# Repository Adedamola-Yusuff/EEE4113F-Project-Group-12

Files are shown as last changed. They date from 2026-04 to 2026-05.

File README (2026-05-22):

# EEE4113F_Group12_PCB
## Overview
This repository was used for Group 12 (of the 2026 EEE4113F course from the University of Cape Town) to collaborate on the design of the B.A.R.B.I.E.

Buoy for<br>
Antarctic<br>
Research and<br>
Basic<br>
Information<br>
Exchange

See the README within each directory for more information.

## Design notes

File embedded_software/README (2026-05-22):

# EEE4113F_Group12_PCB - embedded software
## Overview
This directory contains the software for developing an embedded-program for the BARBIE.

## What is included
This repository includes:
- Simulation files
- Firmware
- Configuration headers

None of the generated compilation files are included.

## Installation & Dependencies
The simulation uses Python 3.13.

The firmware uses the ESP-IDF framework, flashed onto the ESP32 with the PlatformIO workflow and the ESP32's USB-JTAG interface.

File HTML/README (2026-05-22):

# EEE4113F_Group12_PCB - KiCAD files
## Overview
The HTML file contains the UI for the B.A.R.B.I.E called T.E.A.

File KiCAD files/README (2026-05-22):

# EEE4113F_Group12_PCB - KiCAD files
## Overview
This PCB was intended to eventually be sent to [JLCPCB](https://jlcpcb.com/) for printing.

## What is included
This repository includes:
- The Project file
- The Schematic file
- The PCB file
Apologies for the files being so messy.

None of the generated gerber files are included.

## Installation & Dependencies
The files were made with KiCAD 9.0, so the same or a later version of KiCAD is needed to open the files.

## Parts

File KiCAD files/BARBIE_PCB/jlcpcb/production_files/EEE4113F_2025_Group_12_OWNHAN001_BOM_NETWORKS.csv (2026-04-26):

Comment | Designator | Footprint | LCSC | Quantity
ESP32-S3-WROOM-1U-N8 | U1 | ESP32-S3-WROOM-1U_No_holes | C2980297 | 1
ATGM332D-5N71 | U3 | ATGM332D-5NR32 | C46955987 | 1
LORA-CC68-433MHz-TCXO | U2 | LORA-CC68-433MHz-TCXO | C5126744 | 1

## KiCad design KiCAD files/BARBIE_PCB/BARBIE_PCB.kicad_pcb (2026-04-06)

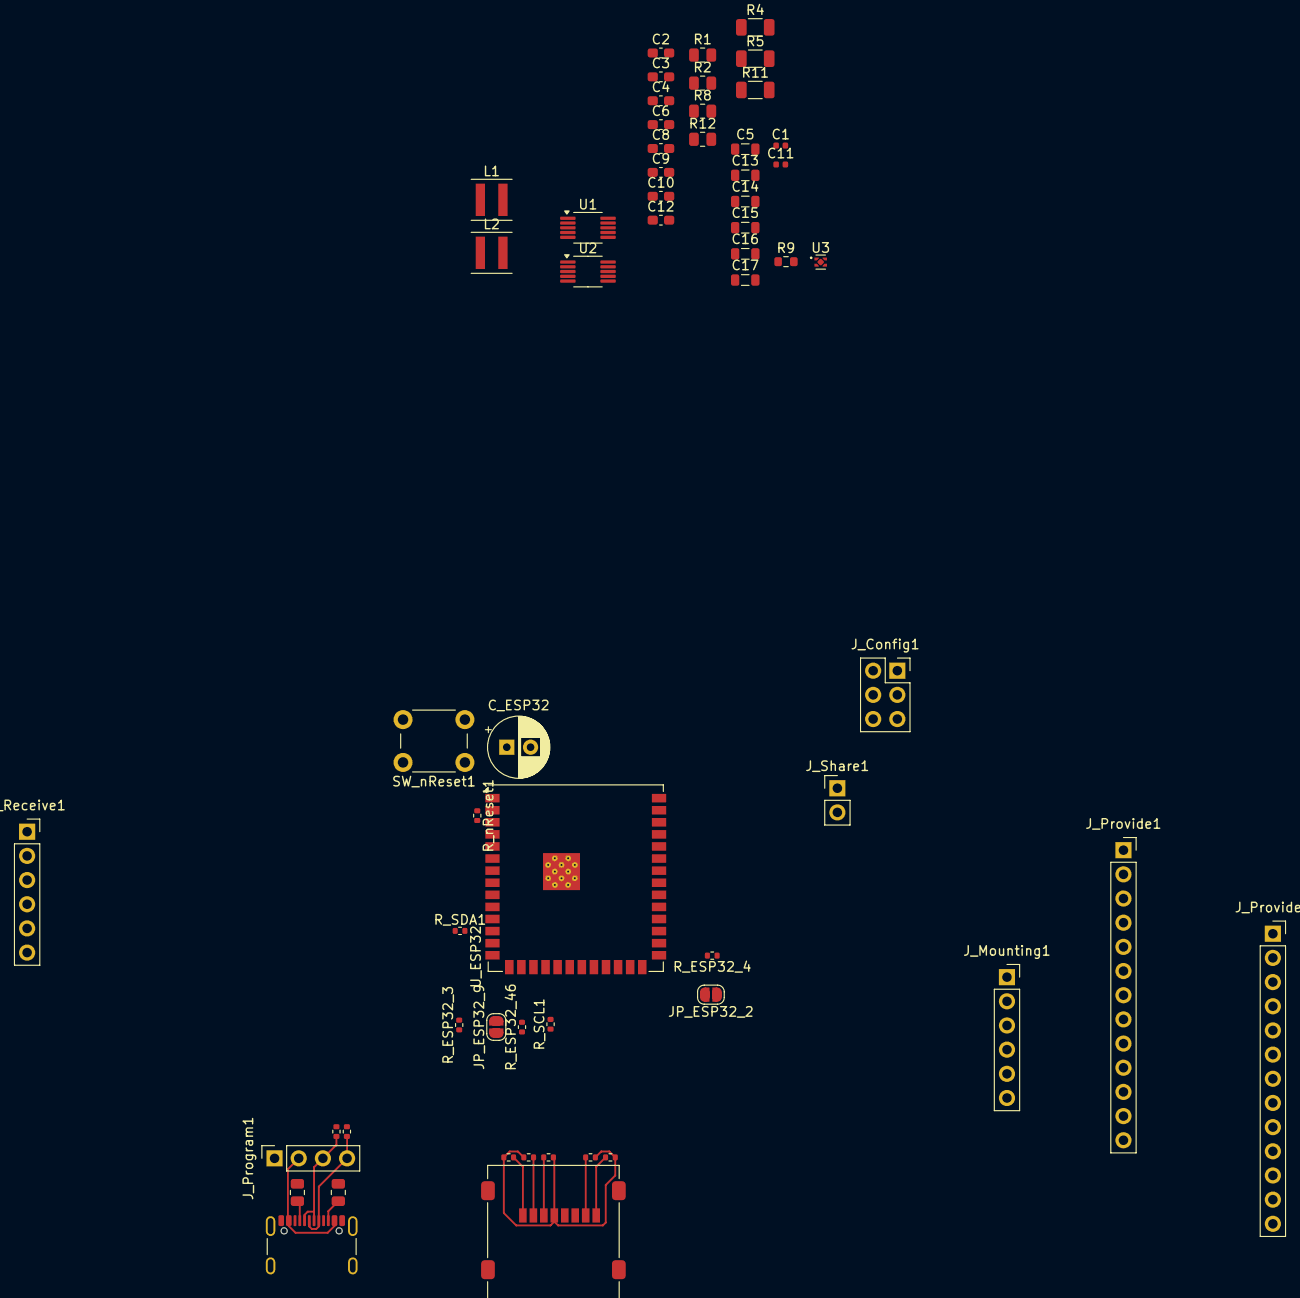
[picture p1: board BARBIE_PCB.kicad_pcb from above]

Board: 2 copper layers, 58 parts (0 on the bottom side), 56 nets.

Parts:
C1, C11: 100nF; L_0402_1005Metric
C2, C3, C4, C6, C8, C9, C10, C12: 10uF; C_0603_1608Metric_Pad1.08x0.95mm_HandSolder
C5, C13, C14, C15, C16, C17: 22uF; L_0805_2012Metric
C_ESP32: C_Polarized_US; CP_Radial_D6.3mm_P2.50mm
JP_ESP32_2, JP_ESP32_9: SolderJumper_2_Open; SolderJumper-2_P1.3mm_Open_RoundedPad1.0x1.5mm
J_Config1: Conn_02x03_Odd_Even; PinSocket_2x03_P2.54mm_Vertical
J_Mounting1: Conn_01x06_Pin; PinSocket_1x06_P2.54mm_Vertical
J_Program1: Conn_01x04_Socket; PinSocket_1x04_P2.54mm_Vertical
J_Provide1, J_Provide2: Conn_01x13; PinSocket_1x13_P2.54mm_Vertical
J_Receive1: Conn_01x06_Pin; PinSocket_1x06_P2.54mm_Vertical
J_SD_Card1: Micro_SD_Card; microSD_HC_Molex_47219-2001
J_Share1: Conn_01x02_Pin; PinHeader_1x02_P2.54mm_Vertical
J_USB_C1: USB_C_Receptacle_USB2.0_16P; USB_C_Receptacle_GCT_USB4105-xx-A_16P_TopMnt_Horizontal
L1, L2: 1.5uH; L_Coilcraft_XxL4020
R1, R8: 470k; R_0805_2012Metric
R2: 150k; R_0805_2012Metric
R4, R5, R11: 10k; R_1206_3216Metric
R9: 120k; R_0603_1608Metric
R12: 220k; R_0805_2012Metric
R_CC1, R_CC2: 5.6kR; R_0805_2012Metric
R_D+1: 22R; R_0402_1005Metric
R_D-1: 22R; R_0402_1005Metric
R_ESP32_3, R_ESP32_4, R_ESP32_46: 1MR; R_0402_1005Metric
R_MISO1: 1MR; R_0402_1005Metric
R_MOSI1: 1MR; R_0402_1005Metric
R_SCL1: 1MR; R_0402_1005Metric
R_SDA1: 1MR; R_0402_1005Metric
R_SD_CARD1, R_SD_CARD2: 1MR; R_0402_1005Metric
R_SD_CARD_CS1: 1MR; R_0402_1005Metric
R_nReset1: 1MR; R_0402_1005Metric
SW_nReset1: SW_Push; SW_PUSH_6mm
U1, U2: TPS60701RNMR; MSOP-10_3x3mm_P0.5mm
U3: TPS3831; Texas_X2SON-4_1x1mm_P0.65mm
U_ESP32: ESP32-S3-WROOM-1; ESP32-S3-WROOM-1U

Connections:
3V3: C4.1, C5.1, C16.1, C17.1, R1.1, U1.7 (VOUT), U1.8 (VOUT)
5V: C12.1, C13.1, C14.1, C15.1, R8.1, U2.7 (VOUT), U2.8 (VOUT)
+3V3: C_ESP32.1, J_Provide1.2, J_Receive1.2, J_SD_Card1.4 (VDD), R_ESP32_3.1, R_ESP32_4.1, R_ESP32_46.1, R_MISO1.1, R_MOSI1.1, R_SCL1.1, R_SDA1.1, R_SD_CARD1.1, R_SD_CARD2.1, R_SD_CARD_CS1.1, R_nReset1.1, U_ESP32.2 (3V3)
+5V: J_Provide1.3, J_Receive1.3
/AD1: J_Provide1.12, U_ESP32.39 (IO1)
/AD2: J_Provide1.13, U_ESP32.38 (IO2)
/AD4: J_Provide2.1, U_ESP32.4 (IO4)
/AD5: J_Provide2.2, U_ESP32.5 (IO5)
/AD6: J_Provide2.3, U_ESP32.6 (IO6)
/AD7: J_Provide2.4, U_ESP32.7 (IO7)
/CS_SD_Card: J_SD_Card1.2 (DAT3/CD), R_SD_CARD_CS1.2, U_ESP32.18 (IO10)
/Config1: J_Config1.1, U_ESP32.34 (IO41)
/Config2: J_Config1.3, U_ESP32.35 (IO42)
/Config3: J_Config1.5, U_ESP32.26 (IO45)
/D14: J_Provide2.5, U_ESP32.22 (IO14)
/D15: J_Provide2.6, U_ESP32.8 (IO15)
/D16: J_Provide2.7, U_ESP32.9 (IO16)
/D17: J_Provide2.8, U_ESP32.10 (IO17)
/D18: J_Provide2.9, U_ESP32.11 (IO18)
/D38: J_Provide2.10, U_ESP32.31 (IO38)
/D39: J_Provide2.11, U_ESP32.32 (IO39)
/D40: J_Provide2.12, U_ESP32.33 (IO40)
/I2C_SCL: J_Provide1.8, J_Receive1.4, R_SCL1.2, U_ESP32.17 (IO9)
/I2C_SDA: J_Provide1.7, J_Receive1.5, R_SDA1.2, U_ESP32.12 (IO8)
/Low_Battery: J_Receive1.6, U_ESP32.25 (IO48)
/SPI_MISO: J_Provide1.9, J_SD_Card1.7 (DAT0), R_MISO1.2, U_ESP32.21 (IO13)
/SPI_MOSI: J_Provide1.10, J_SD_Card1.3 (CMD), R_MOSI1.2, U_ESP32.19 (IO11)
/SPI_SCK: J_Provide1.11, J_SD_Card1.5 (CLK), U_ESP32.20 (IO12)
/UART_RX: J_Provide1.5, U_ESP32.37 (TXD0)
/UART_TX: J_Provide1.6, U_ESP32.36 (RXD0)
/USB_D+: J_Program1.4, J_USB_C1.A6 (D+), J_USB_C1.B6 (D+), R_D+1.2
/USB_D-: J_Program1.3, J_USB_C1.A7 (D-), J_USB_C1.B7 (D-), R_D-1.2
/USB_V: J_Program1.2, J_USB_C1.A4 (VBUS), J_USB_C1.A9 (VBUS), J_USB_C1.B4 (VBUS), J_USB_C1.B9 (VBUS)
/nEnable_Share: J_Share1.1, U_ESP32.24 (IO47)
/nReset: J_Provide1.4, R_nReset1.2, SW_nReset1.1, U_ESP32.3 (EN)
NEW_GND: C1.2, C2.2, C3.2, C4.2, C5.2, C6.2, C8.2, C9.2, C10.2, C11.2, C12.2, C13.2, C14.2, C15.2, C16.2, C17.2, C_ESP32.2, JP_ESP32_2.1 (A), JP_ESP32_9.1 (A), J_Config1.2, J_Config1.4, J_Config1.6, J_Program1.1, J_Provide1.1, J_Provide2.13, J_Receive1.1, J_SD_Card1.6 (VSS), J_Share1.2, J_USB_C1.A1 (GND), J_USB_C1.A12 (GND), J_USB_C1.B1 (GND), J_USB_C1.B12 (GND), R2.2, R11.2, R_CC1.2, R_CC2.2, SW_nReset1.2, U1.4 (GND), U1.6 (FB2), U1.10 (PGND), U2.4 (GND), U2.6 (FB2), U2.10 (PGND), U_ESP32.1 (GND), U_ESP32.40 (GND), U_ESP32.41 (GND)
unnamed: JP_ESP32_2.2 (B), R_ESP32_4.2, U_ESP32.27 (IO0)
unnamed: JP_ESP32_9.2 (B), R_ESP32_46.2, U_ESP32.16 (IO46)
unnamed: J_SD_Card1.8 (DAT1), R_SD_CARD1.2
unnamed: J_SD_Card1.1 (DAT2), R_SD_CARD2.2
unnamed: J_USB_C1.A5 (CC1), R_CC1.1
unnamed: J_USB_C1.B5 (CC2), R_CC2.1
unnamed: R9.2, R11.1
unnamed: R8.2, R12.1
unnamed: R4.2, U1.1 (PS/SYNC)
unnamed: R1.2, R2.1, U1.5 (FB)
unnamed: L1.1, U1.9 (L2)
unnamed: C1.1, U1.3 (VAUX)
unnamed: R5.2, U2.1 (PS/SYNC)
unnamed: R9.1, R12.2, U2.5 (FB)
unnamed: L2.1, U2.9 (L2)
unnamed: C11.1, U2.3 (VAUX)
unnamed: R_ESP32_3.2, U_ESP32.15 (IO3)
unnamed: R_D+1.1, U_ESP32.14 (USB_D+)
unnamed: R_D-1.1, U_ESP32.13 (USB_D-)
V_BATTERY: C2.1, C3.1, C6.1, C8.1, C9.1, C10.1, R4.1, R5.1, U3.4 (VDD)

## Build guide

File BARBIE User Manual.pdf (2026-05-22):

# BARBIE User Manual

DESCRIPTION
The BARBIE (Buoy for Antarctic Research and Basic Information Exchange) is a device intended to address some common concerns with regards to research in the Antarctic. In particular, it attempts to address:
- Power supply
- Data storage
- Data transmission / retrieval
- Data security
- Water proofing
- Protection against collisions
The project’s documentation, PCB design and code can be found on GitHub: https://github.com/Adedamola-Yusuff/EEE4113F-Project-Group-12

TYPICAL APPLICATION
The BARBIE interfaces internally with a custom sensor module (designed by the user). This sensor module receives power from the BARBIE, and sends data over the I2C interface. The BARBIE automatically stores this data in the micro SD card, and eventually distributes the data to other nearby BARBIEs. The BARBIE will also transmit the data to the TEA software over satellite, along with its GPS location. Using the TEA software nearby, a data-dump can be requested, in which the BARBIE dumps all of its data over a Wi-Fi connection to the user’s device.

NOTES
The BARBIE is still experimental, and not fully tested.
2025 May 1 | EEE4113F - Group 12

DIMENSIONS

Dimension | Value | Unit
Height | 500 | mm
Diameter | 272 | mm

BATTERY SPECIFICATIONS

Characteristic | Value | Unit
Minimum Voltage | 6 | V
Maximum Voltage | 15 | V
Recommended Chemistry | Lithium Titanate Oxide | -

NETWORKING PERFORMANCE

Protocol | Metric | Value | Unit
Wi-Fi | Maximum Range | 10 | m
Wi-Fi | Data Rate | 250 | kb/s
Global Positioning System | Tolerance | 10 | m

POWERING SENSOR MODULE

Supply | Rating | Value | Unit
Primary | Voltage | 3.3 | V
Primary | Current | 300 | mA
Secondary | Voltage | 5 | V
Secondary | Current | 300 | mA

COLLECTING DATA
The onboard ESP32 is in light sleep most of the time. The sensor module is required to raise the “data ready” pin to wake up the ESP32. Give 5 milliseconds.

After being woken up, the ESP32 gives the sensor module 500 milliseconds to send the header of the I2C Data Format (the write address and the payload length). The ESP32 then gives another 500 milliseconds to transmit the payload. Failure to meet either of these deadlines will result in the ESP32 discarding what it received and going back to sleep.

The write address 0x01 corresponds to giving data.
The write address 0x02 corresponds to giving instructions (not yet implemented).

DATA FORMATS
Data packet
0x00 | BARBIE ID
0x01 | Sequence Number
0x02 - 0xFD | Data from Sensor Module
0xFE - 0xFF | 16-bit Cyclic Redundancy Check / IBM Convention

I2C Data Format
0x00 | Write Address
0x01 | Payload Length
0x02 - … | Payload

CONFIGURABLE PROPERTIES
Several behaviours/properties of the BARBIE can be configured by flashing the onboard ESP32 with a modified software_config.h file.
Property | Macro Name | Default Value | Notes
Address of BARBIE when acting as an I2C slave | I2C_SLAVE_ADDRESS | 0x67 | -
Sharing data with peers | DATA_SHARING | N/A (enabled) | Comment out this macro to stop the BARBIE from sharing data to peers
Period of sharing data with peers | SHARE_PERIOD | 1ULL*60*60* 1000*1000 | To use this macro to modify the period, the macro SHARE_PERIOD_OVERRIDE must be uncommented
Sending GPS location | SEND_GPS | N/A (enabled) | Comment out this macro to stop the BARBIE from sending its GPS
Transmitting data over satellite | TRANSMIT_DATA | N/A (enabled) | Comment out this macro to stop the BARBIE from sending data over satellite
Period of transmitting data and GPS over satellite | SATELLITE_PERIOD | 24ULL*60*60 *1000*1000 | -
The identification number of the BARBIE | DEVICE_ID | 0 | To use this macro to modify the ID, the macro DEVICE_ID_OVERRIDE must be uncommented
Filepath to where data is stored on micro SD card | DATA_FILENAME_PATH | "/sdcard/da ta.bin" | -

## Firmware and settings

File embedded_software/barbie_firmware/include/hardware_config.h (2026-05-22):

/*
    Header file describing the hardware configurations
    Made by: Neo Vorsatz

    ESP32-S3-WROOM-1U-N8
    Datasheet: https://documentation.espressif.com/esp32-s3-wroom-1_wroom-1u_datasheet_en.html
    Technical Reference Manual v1.8: https://documentation.espressif.com/esp32-s3_technical_reference_manual_en.pdf

    Features
    ROM: 384 KB
    SRAM: 512 KB
    SRAM in RTC: 16 KB
    Clock: 40 MHz crystal oscillator
    Flash: 8 MB (Quad SPI) 
*/

// Header guard
#ifndef HARDWARE_CONFIG_H
#define HARDWARE_CONFIG_H

// ESP32 PIN CONNECTIONS ================================

// Strapping pins
#define IO0 0 // [GPIO 0], RTC GPIO 0, firmware download
#define IO3 3 // [GPIO 3], RTC GPIO 3, touch 3, ADC 1 channel 2, JTAG behaviour

// Configuration pins
#define PIN_ID_0 1 // [GPIO 1], RTC GPIO 1, touch 1, ADC 1 channel 0
#define PIN_ID_1 2 // [GPIO 2], RTC GPIO 2, touch 2, ADC 1 channel 1
#define PIN_ID_2 6 // [GPIO 6], RTC GPIO 6, touch 6, ADC 1 channel 5
#define PIN_SHARE_DATA 7 // [GPIO 7], RTC GPIO 7, touch 7, ADC 1 channel 6

// Low battery
#define PIN_LOW_BATTERY 45 // [GPIO 45]

// I2C (chosen because they are the Arduino defaults)
#define PIN_I2C_SDA 46 // [GPIO 46]
#define PIN_I2C_SCL 9 // [GPIO 9], RTC GPIO 9, touch 9, ADC 1 channel 8, FSPIHD, SUBSPIHD
#define PIN_SENSOR_DATA_READY 8 // [GPIO 8], RTC GPIO 8, touch 8, ADC 1 channel 7, SUBSPICS1

// SPI (chosen because they are the Arduino defaults)
#define CS_SD_CARD 10 // [GPIO 10], RTC GPIO, touch 10, ADC 1 channel 9, FSPICS0, FSPIIO4, SUBSPICS0
#define LORA_MOSI 11 // [GPIO 11], RTC GPIO 11, touch 11, ADC 2 channel 0, FSPID, FSPIIO5, SUBSPID
#define LORA_SCK 12 // [GPIO 12], RTC GPIO 12, touch 12, ADC 2 channel 1, FSPICLK, FSPIIO6, SUBSPICLK
#define LORA_MISO 13 // [GPIO 13], RTC GPIO 13, touch 13, ADC 2 channel 2, FSPIQ, FSPIIO7, SUBSPIQ

// USB
#define USB_DP 19 // GPIO 19, RTC GPIO 19, ADC 2 channel 8, [USB D-], U1RTS, CLK out 2
#define USB_DM 20 // GPIO 20, RTC GPIO 20, ADC 2 channel 9, [USB D+], U1CTS, CLK out 1

// OCTAL flash/PSRAM
#define OCTAL_SPIIO6 35 // [GPIO 35], SPIIO6, FSPID, SUBSPID
#define OCTAL_SPIIO7 36 // [GPIO 36], SPIIO7, FSPICLK, SUBSPICLK
#define OCTAL_SPIDQS 37 // [GPIO 37], SPIDQS, FSPIQ, SUBSPIQ

// JTAG interface
#define IO39 39 // GPIO 39, [MTCK], SUBSPICS1, CLK out 3
#define IO40 40 // GPIO 40, [MTDO], CLK out 2
#define IO41 41 // GPIO 41, [MTDI], CLK out 1
#define IO42 42 // GPIO 42, [MTMS]

// UART
#define TXD0 43 // GPIO 43, UART TX
#define RXD0 44 // GPIO 44, UART RX

// LoRa
#define LORA_NSS 5 // [GPIO 5], RTC GPIO 5, touch 5, ADC 1 channel 4
#define LORA_NRESET 14 // [GPIO 14], RTC GPIO 14, touch 14, DC 2 channel 3, FSPIWP, FSPIDQS, SUBSPIWP
#define LORA_BUSY 16 // [GPIO 16], RTC GPIO 16, ADC 2 channel 5, U0RTS, XTAL 32K N
#define LORA_DIO1 15 // [GPIO 15], RTC GPIO 15, ADC 2 channel 4, U0RTS, XTAL 32K P

// GPS
#define GPS_TXD 17 // [GPIO 17], RTC GPIO 17, ADC 2 channel 6, U1TXD
#define GPS_RXD 18 // [GPIO 18], RTC GPIO 18, ADC 2 channel 7, U1RXD, CLK out 3

// Satellite
#define SAT_TXD 4 // [GPIO 4], RTC GPIO 4, touch 4, ADC 1 channel 3
#define SAT_RXD 21 // [GPIO 21], RTC GPIO 21

// ================================

#endif

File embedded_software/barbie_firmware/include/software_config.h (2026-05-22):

/*
    Header file describing the software configurations
    Made by: Neo Vorsatz
*/

// Header guard
#ifndef SOFTWARE_CONFIG_H
#define SOFTWARE_CONFIG_H

// Includes
#include <stdbool.h>

// RECONFIGURATION FOR CLIENT ================================

// I2C Interface
#define I2C_SLAVE_ADDRESS 0x67 // I2C slave address

// Barbie-to-Barbie data sharing
#define DATA_SHARING // comment this out to stop device from sharing data via LoRa
// #define SHARE_PERIOD_OVERRIDE // uncomment this to override the data sharing period
#define SHARE_PERIOD (1ULL*60*60*1000*1000) // new data sharing period, if overriden (microseconds)

// Satellite data transmission
#define SEND_GPS // comment this out to stop device from sending its GPS
#define TRANSMIT_DATA // comment this out to stop device from sending its data over satellite
#define SATELLITE_PERIOD (24ULL*60*60*1000*1000) // 24 hours

// Device ID
// #define DEVICE_ID_OVERRIDE // uncomment this to override the device's ID
#define DEVICE_ID 0 // new device ID, if overriden (from 0 to 7)

// SD card data storage
#define DATA_FILENAME_PATH "/sdcard/data.bin" // filepath of the data file

// ================================
// DEBUGGING ================================

#define DEBUG // uncomment this to enable debug logging

// ================================
// FIXED CONSTANTS ================================

// Data sharing periods
#define SHARE_PERIOD_0 (120ULL*60*1000*1000) // 120 minutes
#define SHARE_PERIOD_1 (119ULL*60*1000*1000) // 119 minutes
#define SHARE_PERIOD_2 (118ULL*60*1000*1000) // 118 minutes
#define SHARE_PERIOD_3 (117ULL*60*1000*1000) // 117 minutes
#define SHARE_PERIOD_4 (116ULL*60*1000*1000) // 116 minutes
#define SHARE_PERIOD_5 (115ULL*60*1000*1000) // 115 minutes
#define SHARE_PERIOD_6 (114ULL*60*1000*1000) // 114 minutes
#define SHARE_PERIOD_7 (113ULL*60*1000*1000) // 113 minutes

// ================================

#endif

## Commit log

2026-04-06 Added a voltage regulators and a switch. Still need to finish adding footprints.
    [BARBIE_PCB.kicad_sch]
2026-04-06 Starting PCB layout and tracing
    [BARBIE_PCB.kicad_pcb, BARBIE_PCB.kicad_sch]
2026-04-07 NETWORKS SUBSYSTEM
    Complete PCB design of my networks subsystem
    [ATGM332D-5NR321_ATGM332D-5NR32.schdoc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]
2026-04-08 Integrated Hannah's schematic into the main schematic
    [BARBIE_PCB-B_Cu.gbr, BARBIE_PCB-B_Mask.gbr, BARBIE_PCB-B_Paste.gbr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]
2026-04-08 Integrated Hannah's PCB onto the main circuit. Now I have to do a force push.
    [BARBIE_PCB.kicad_sch]
2026-05-11 Pin configuration
2026-05-18 Update README with project component descriptions
    Added descriptions for HTML, KiCAD, and embedded software sections.
